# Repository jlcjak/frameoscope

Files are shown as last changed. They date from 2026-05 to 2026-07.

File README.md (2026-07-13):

# frameoscope
oscilloscope expansion card / module for framework laptops 

[frame.fasterscope.com](https://frame.fasterscope.com)

## Tech Specs
- sampling rate: 40MSPS
- bandwidth: 10MHz
- resolution: 8bit
- interface: usb2
- front end Rin: 8.5KOhm
- front end Cin: ~5pF
- input voltage: 0-5V (protected from reverse and high voltage)

## How to use
I have built and tested frameoscope, it works! I made it compatible with ngscopeclient.
Here is how to use it:
1. install [ngscopeclient](https://github.com/ngscopeclient/scopehal-apps/releases/)
2. plug in frameoscope and run: `curl -fsSL frame.fasterscope.com/install.sh | bash` (Source code in "/software")

That's it, now ngscopeclient should see frameoscope as an oscilloscope

to uninstall: `curl -fsSL frame.fasterscope.com/uninstall.sh | bash`

this works on ubuntu 24, for other distros clone this repo and ask codex(/your agent of choice) to make it work

The script installs, starts and enables a service that will flash frameoscope upon insertion
and start a bridge that translates the stream into ngscopeclient compatible packets

## Remarks
- The board is mainly comprimized of a TI adc, an iCE40 fpga and a usb PHY (FT232H).
- The fpga is used as an protocol tranlator between the busses on the usb PHY and adc.
- You can program the fpga directly over usb, through FT232H.
- There is no flash on the fpga so you need to reprogram it on reset or use iCE nvcm

## manufacturing
- all components are sourcable from lcsc, for easy assembly in china.
- use a 0.8mm board so you can solder on the usb connector

Nextpcb sponsored the first iteration of this project, thanks nextpcb. you can easily use them to make this for very cheap. They are professional, fast and cheap. [nextpcb.com](https://www.nextpcb.com/?code=Jak)

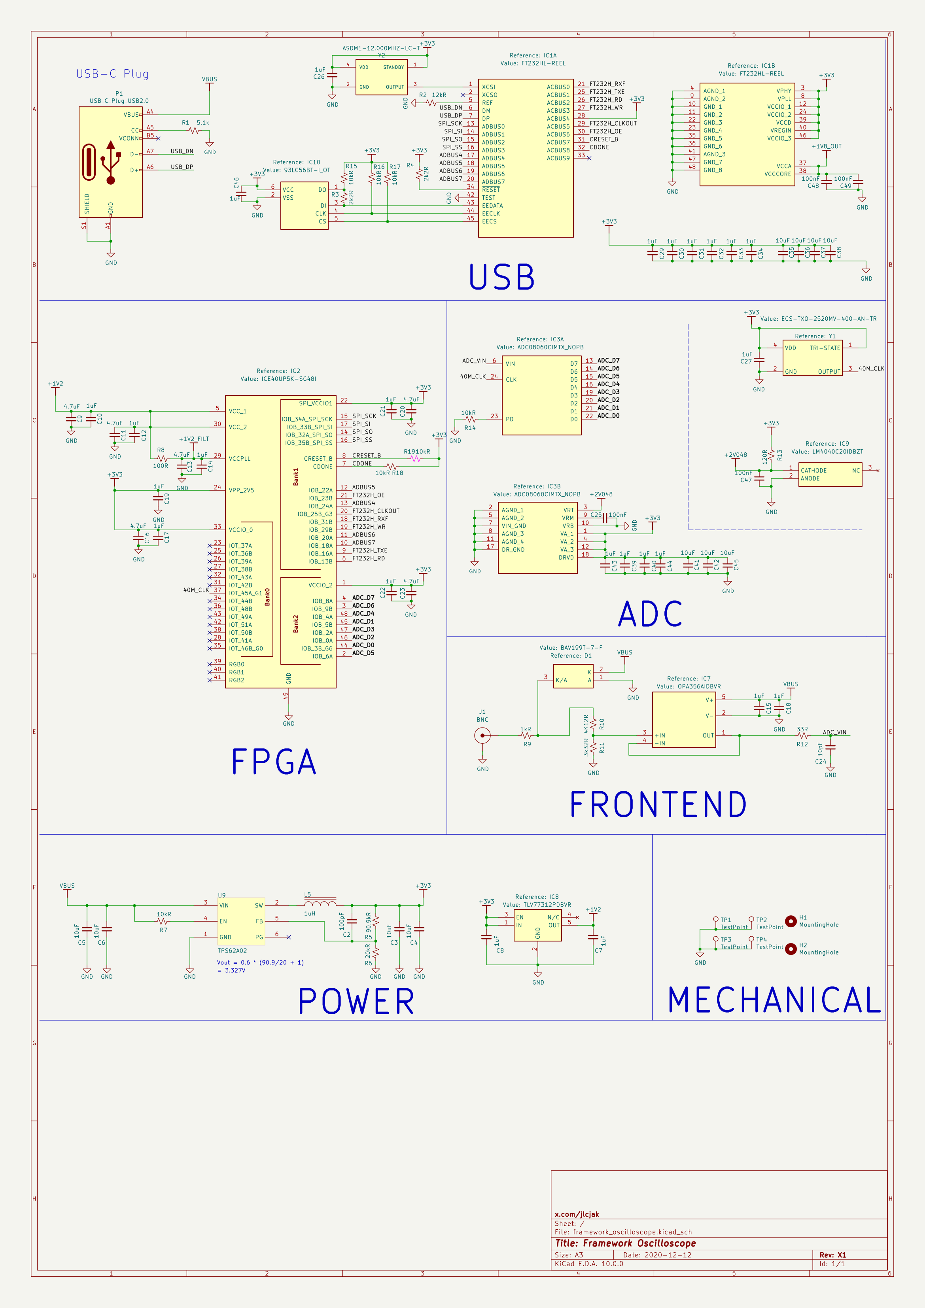
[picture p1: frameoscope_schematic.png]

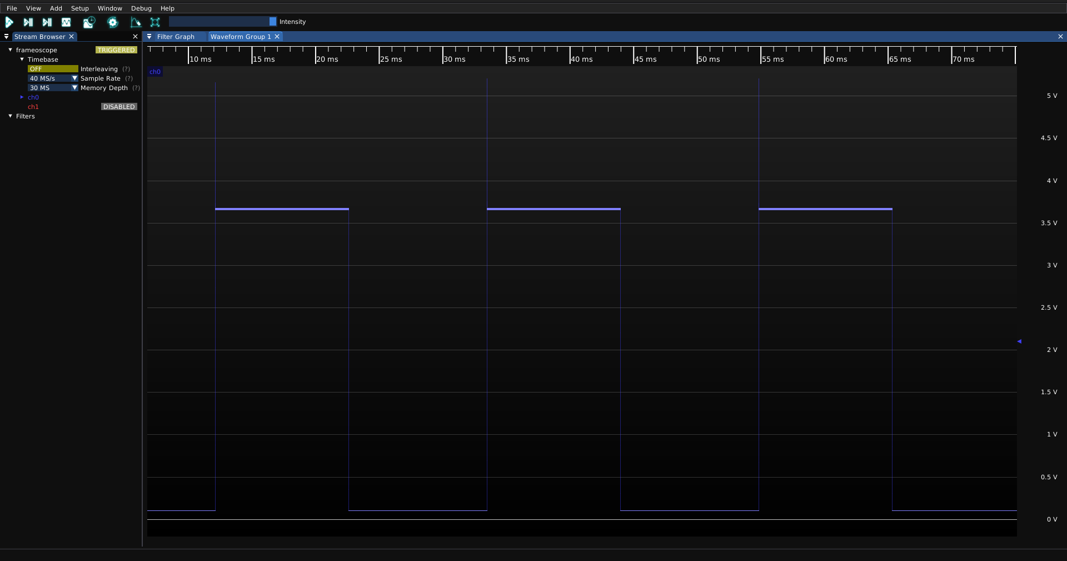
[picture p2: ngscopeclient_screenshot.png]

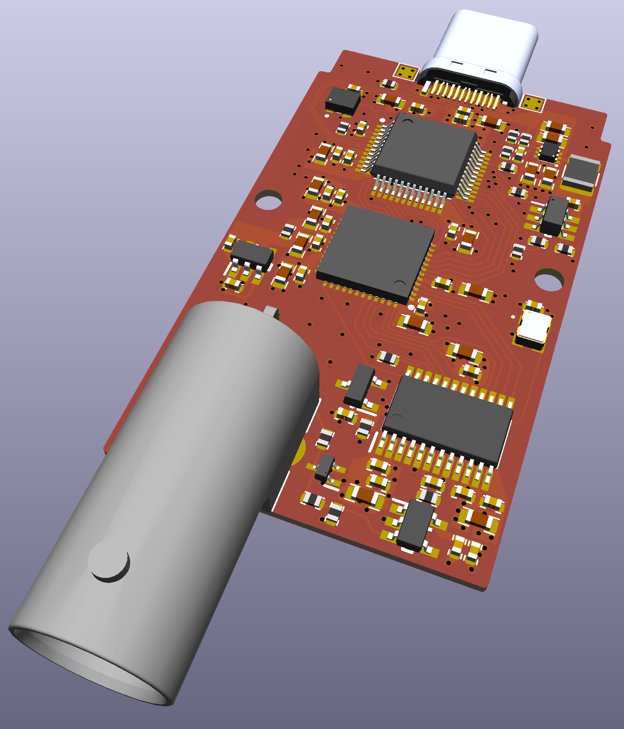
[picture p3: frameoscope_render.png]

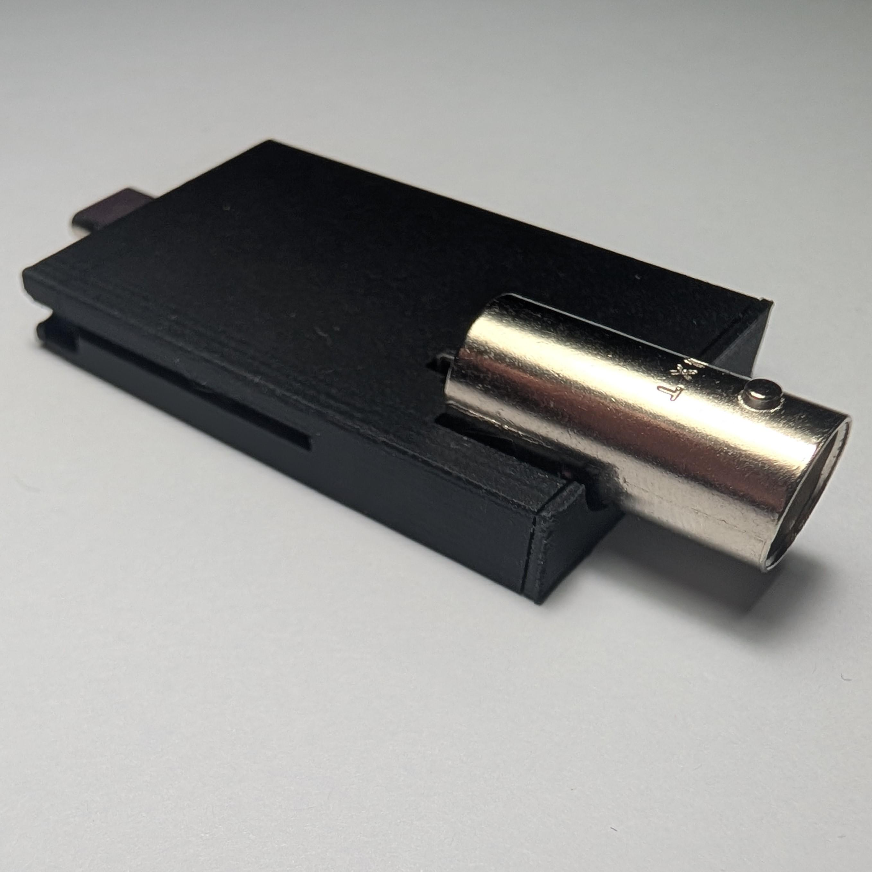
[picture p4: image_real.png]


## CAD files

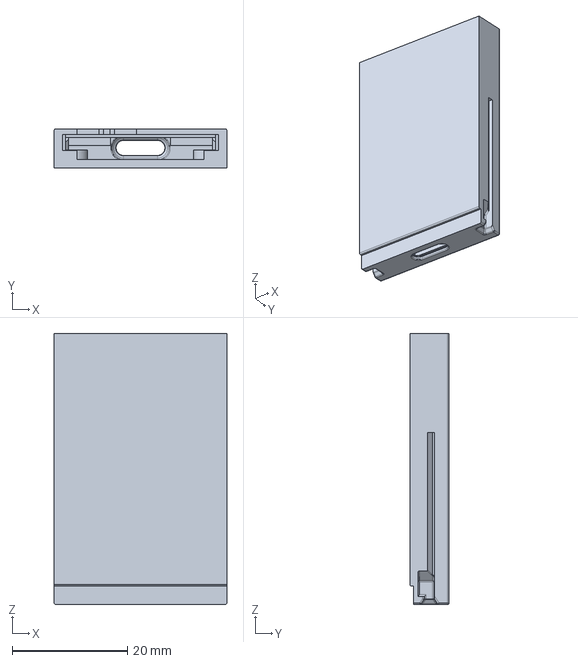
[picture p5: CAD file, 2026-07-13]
case_3d_models/case.step
30.0 x 6.80 x 47.0 mm

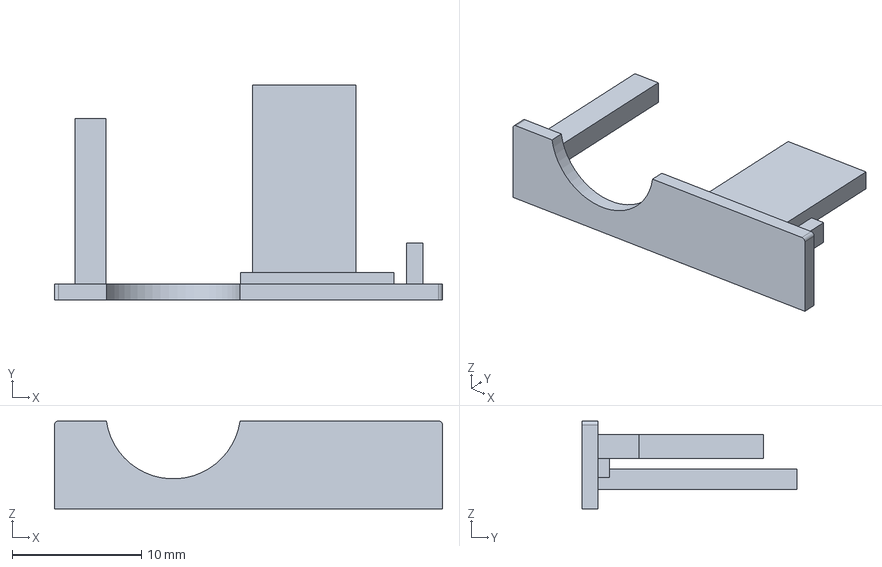
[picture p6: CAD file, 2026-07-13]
case_3d_models/case_cover.step
30.0 x 16.6 x 6.80 mm

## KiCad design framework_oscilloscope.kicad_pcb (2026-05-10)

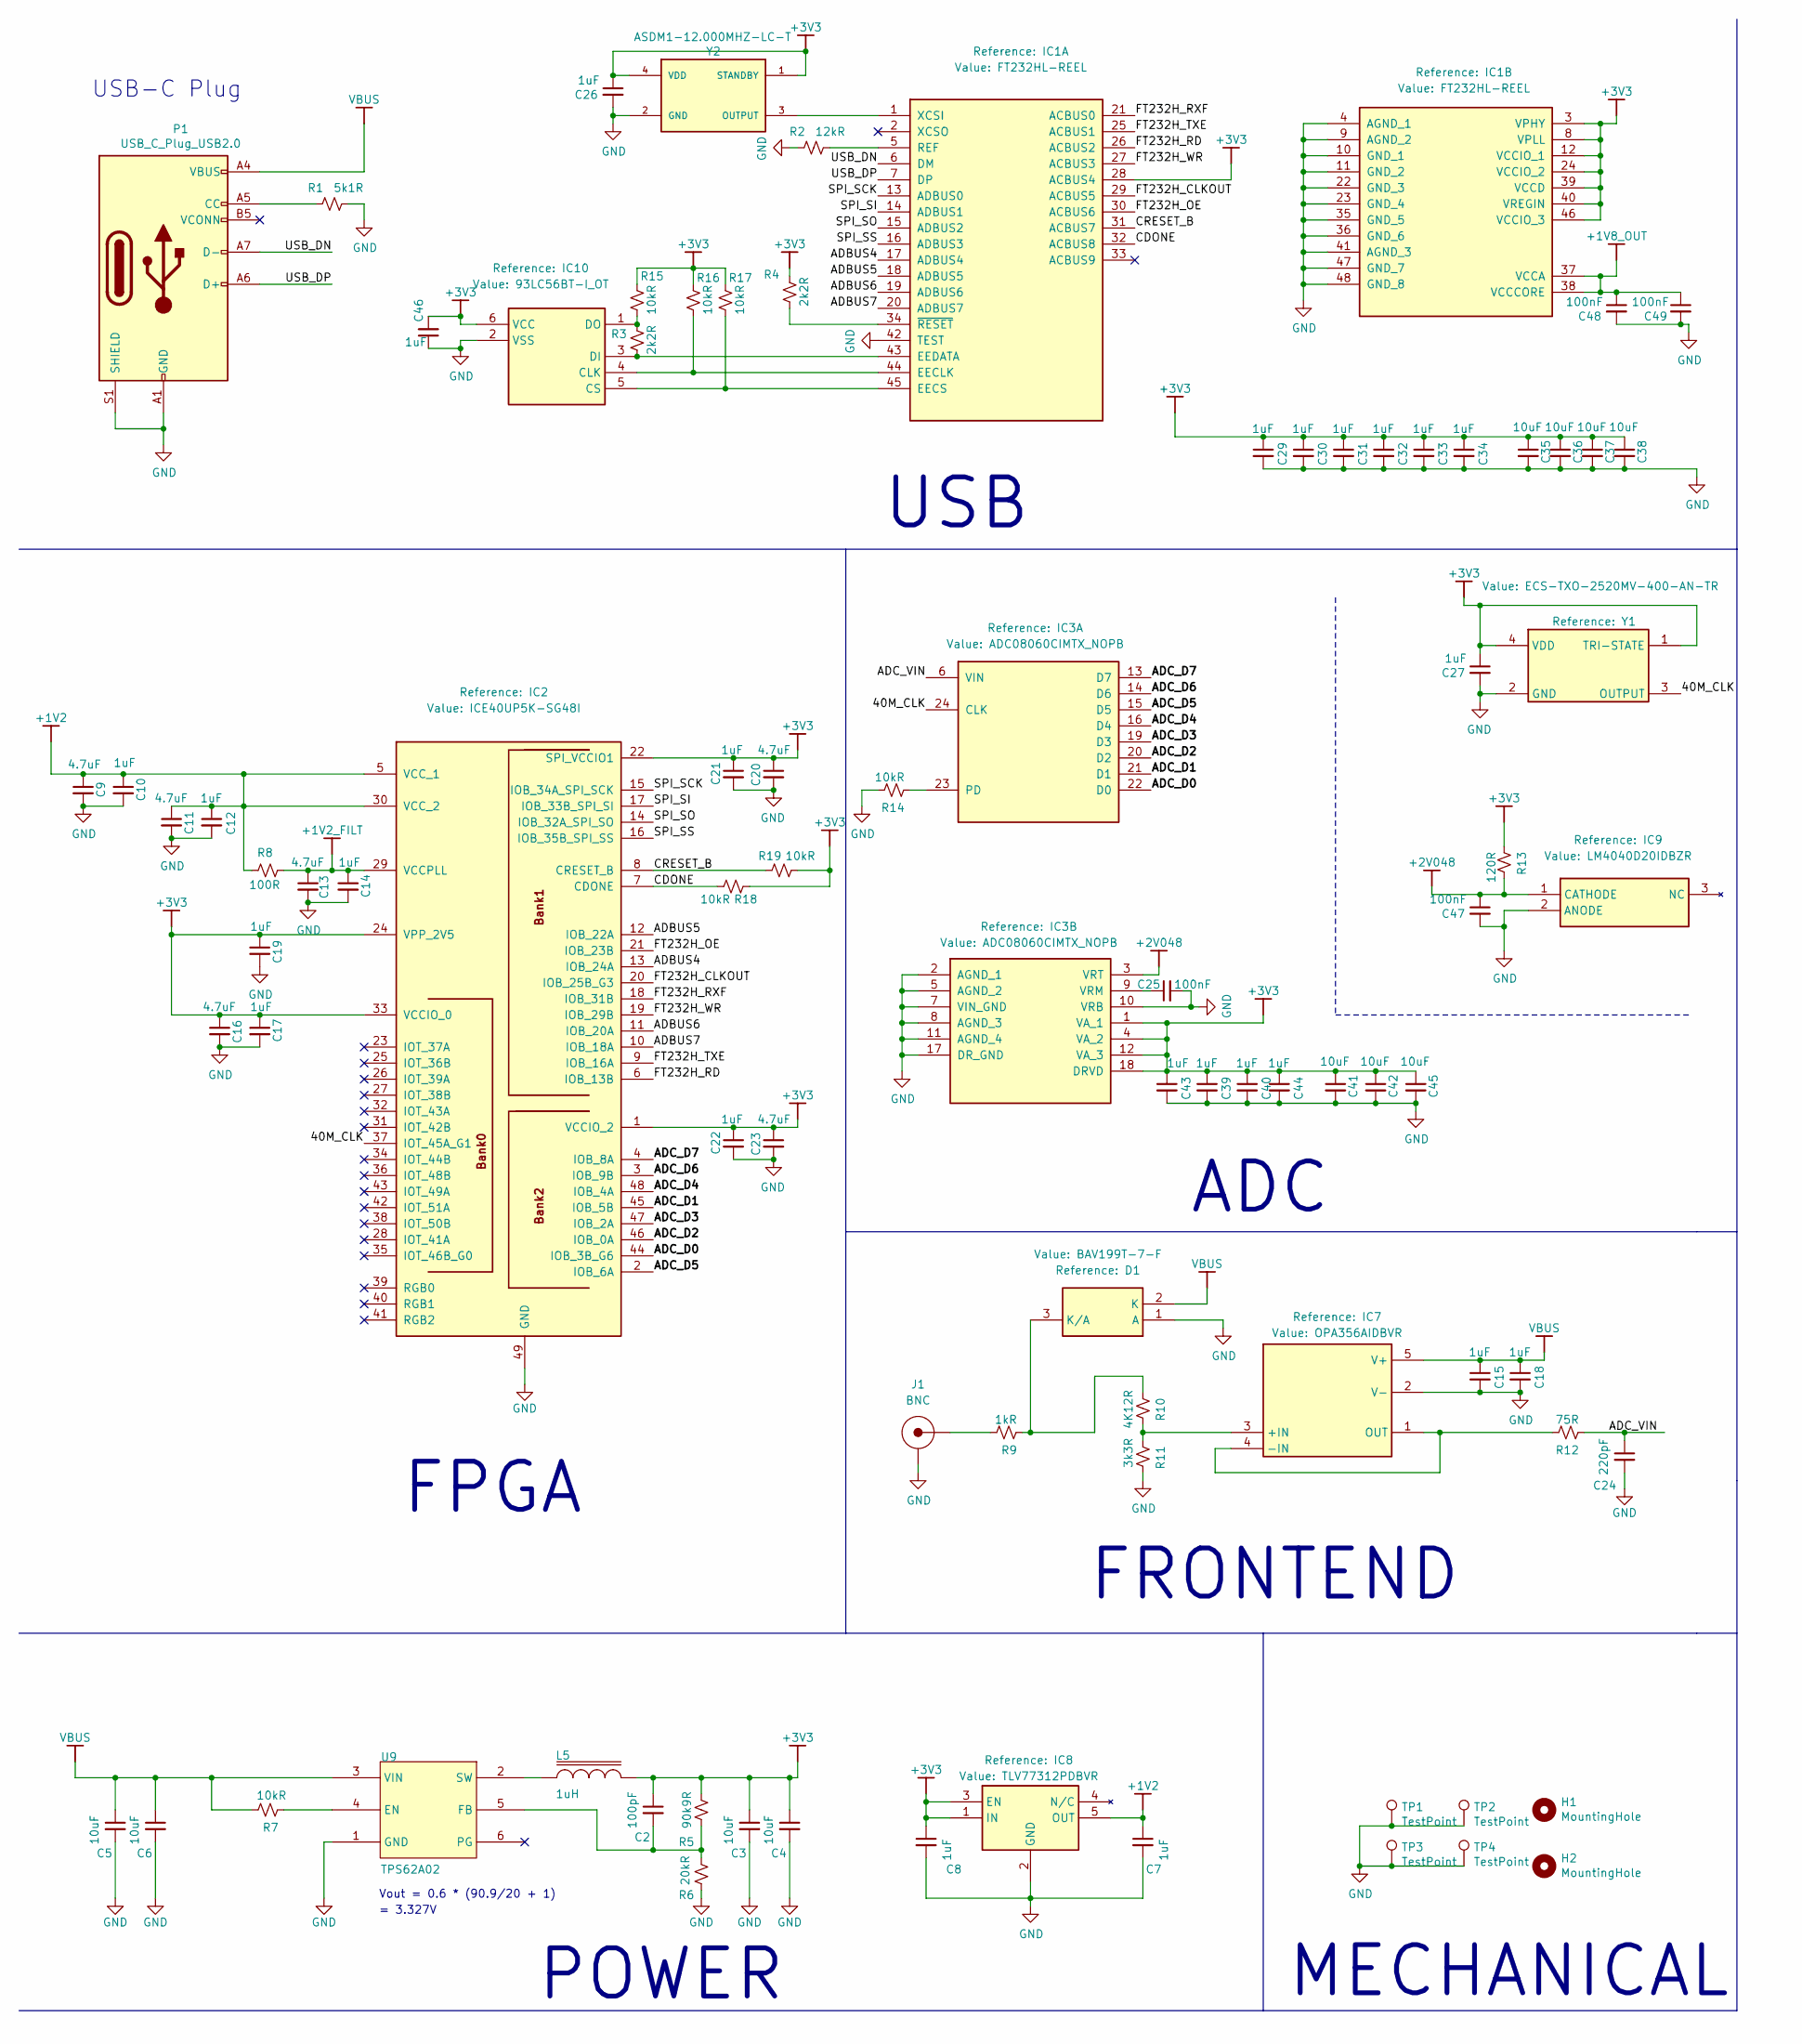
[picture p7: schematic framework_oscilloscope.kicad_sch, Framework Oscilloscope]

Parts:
C2: 100pF; 0402_1005Metric_CAP; MANUFACTURER PART NUMBER CC0402JRNPO9BN101
C3, C4, C5, C6, C35, C36, C37, C38, C41, C42, C45: 10uF; 0603_1608Metric_CAP; MANUFACTURER PART NUMBER CL10A106MQ8NNNC
C7, C8, C10, C12, C14, C15, C17, C18, C19, C21, C22, C26, C27, C29, C30, C31, C32, C33, C34, C39, C40, C43, C44, C46: 1uF; 0402_1005Metric_CAP; MANUFACTURER PART NUMBER CL05A105KO5NNNC
C9, C11, C13, C16, C20, C23: 4.7uF; 0603_1608Metric_CAP; MANUFACTURER PART NUMBER CL10A475KP8NNNC
C24: 220pF; 0402_1005Metric_CAP; MANUFACTURER PART NUMBER CC0402JRNPO9BN221
C25, C47, C48, C49: 100nF; 0402_1005Metric_CAP; MANUFACTURER PART NUMBER CL05B104KO5NNNC
D1: BAV199T-7-F; SOT50P160X90-3N; MANUFACTURER PART NUMBER BAV199T-7-F
H1, H2: MountingHole; MountingHole_2.2mm_M2
IC1: FT232HL-REEL; QFP50P900X900X160-48N; MANUFACTURER PART NUMBER FT232HL-REEL
IC2: ICE40UP5K-SG48I; QFN50P700X700X100-49N-D; MANUFACTURER PART NUMBER ICE40UP5K-SG48I
IC3: ADC08060CIMTX_NOPB; SOP65P640X120-24N; MANUFACTURER PART NUMBER ADC08060CIMTX/NOPB
IC7: OPA356AIDBVR; SOT95P280X145-5N; MANUFACTURER PART NUMBER OPA356AIDBVR
IC8: TLV77312PDBVR; SOT95P280X145-5N; MANUFACTURER PART NUMBER TLV77312PDBVR
IC9: LM4040D20IDBZR; SOT95P237X112-3N; MANUFACTURER PART NUMBER LM4040D20IDBZR
IC10: 93LC56BT-I_OT; SOT95P270X145-6N; MANUFACTURER PART NUMBER 93LC56BT-I/OT
J1: BNC; MOL_0731000105; MANUFACTURER PART NUMBER 73100-0105
L5: 1uH; 1210_3225Metric; MANUFACTURER PART NUMBER SRP3212-1R0M
P1: USB_C_Plug_USB2.0; USB_C_Plug_Molex_105444; MANUFACTURER PART NUMBER 105444-0001
R1: 5k1R; 0402_1005Metric; MANUFACTURER PART NUMBER RC0402FR-075K1L
R2: 12kR; 0402_1005Metric; MANUFACTURER PART NUMBER ERA2AEB123X
R3, R4: 2k2R; 0402_1005Metric; MANUFACTURER PART NUMBER RC0402JR-072K2L
R5: 90k9R; 0402_1005Metric; MANUFACTURER PART NUMBER RC0402FR-0790K9L
R6: 20kR; 0402_1005Metric; MANUFACTURER PART NUMBER RC0402FR-0720KL
R7, R14, R15, R16, R17, R18, R19: 10kR; 0402_1005Metric; MANUFACTURER PART NUMBER RC0402JR-0710KL
R8: 100R; 0402_1005Metric; MANUFACTURER PART NUMBER RC0402FR-07100RL
R9: 1kR; 0402_1005Metric; MANUFACTURER PART NUMBER RT0402FRE071KL
R10: 4K12R; 0402_1005Metric; MANUFACTURER PART NUMBER RT0402BRD074K12L
R11: 3k3R; 0402_1005Metric; MANUFACTURER PART NUMBER RT0402BRD073K3L
R12: 75R; 0402_1005Metric; MANUFACTURER PART NUMBER RC0402FR-0775RL
R13: 120R; 0402_1005Metric; MANUFACTURER PART NUMBER RC0402FR-0775RL
TP1, TP2, TP3, TP4: TestPoint; TestPoint_Pad_1.5x1.5mm
U9: TPS62A02; TI_SOT563_DRL0006A; MANUFACTURER PART NUMBER TPS62A02DRLR
Y1: ECS-TXO-2520MV-400-AN-TR; ECSTXO252033250ANTR; MANUFACTURER PART NUMBER ECS-TXO-2520MV-400-AN-TR
Y2: ASDM1-12.000MHZ-LC-T; XTAL_ASDM1-12.000MHZ-LC-T; MANUFACTURER PART NUMBER ASDM1-12.000MHZ-LC-T

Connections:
+1V2: C7.1, C9.1, C10.1, C11.1, C12.1, IC2.5 (VCC_1), IC2.30 (VCC_2), IC8.5 (OUT), R8.2
+1V2_FILT: C13.1, C14.1, IC2.29 (VCCPLL), R8.1
+1V8_OUT: C48.1, C49.1, IC1.37 (VCCA), IC1.38 (VCCCORE)
+2V048: C47.1, IC3.3 (VRT), IC9.1 (CATHODE), R13.1
+3V3: C2.1, C3.1, C4.1, C8.1, C16.1, C17.1, C19.1, C20.1, C21.1, C22.1, C23.1, C26.1, C27.1, C29.1, C30.1, C31.1, C32.1, C33.1, C34.1, C35.1, C36.1, C37.1, C38.1, C39.1, C40.1, C41.1, C42.1, C43.1, C44.1, C45.1, C46.2, IC1.3 (VPHY), IC1.8 (VPLL), IC1.12 (VCCIO_1), IC1.24 (VCCIO_2), IC1.28 (ACBUS4), IC1.39 (VCCD), IC1.40 (VREGIN), IC1.46 (VCCIO_3), IC2.1 (VCCIO_2), IC2.22 (SPI_VCCIO1), IC2.24 (VPP_2V5), IC2.33 (VCCIO_0), IC3.1 (VA_1), IC3.4 (VA_2), IC3.12 (VA_3), IC3.18 (DRVD), IC8.1 (IN), IC8.3 (EN), IC10.6 (VCC), L5.2, R4.2, R5.2, R13.2, R15.2, R16.2, R17.2, R18.1, R19.1, Y1.1 (TRI-STATE), Y1.4 (VDD), Y2.1 (STANDBY), Y2.4 (VDD)
/40M_CLK: IC2.37 (IOT_45A_G1), IC3.24 (CLK), Y1.3 (OUTPUT)
/ADBUS4: IC1.17 (ADBUS4), IC2.13 (IOB_24A)
/ADBUS5: IC1.18 (ADBUS5), IC2.12 (IOB_22A)
/ADBUS6: IC1.19 (ADBUS6), IC2.11 (IOB_20A)
/ADBUS7: IC1.20 (ADBUS7), IC2.10 (IOB_18A)
/ADC_D0: IC2.44 (IOB_3B_G6), IC3.22 (D0)
/ADC_D1: IC2.45 (IOB_5B), IC3.21 (D1)
/ADC_D2: IC2.46 (IOB_0A), IC3.20 (D2)
/ADC_D3: IC2.47 (IOB_2A), IC3.19 (D3)
/ADC_D4: IC2.48 (IOB_4A), IC3.16 (D4)
/ADC_D5: IC2.2 (IOB_6A), IC3.15 (D5)
/ADC_D6: IC2.3 (IOB_9B), IC3.14 (D6)
/ADC_D7: IC2.4 (IOB_8A), IC3.13 (D7)
/ADC_VIN: C24.1, IC3.6 (VIN), R12.2
/CDONE: IC1.32 (ACBUS8), IC2.7 (CDONE), R18.2
/CRESET_B: IC1.31 (ACBUS7), IC2.8 (CRESET_B), R19.2
/FT232H_CLKOUT: IC1.29 (ACBUS5), IC2.20 (IOB_25B_G3)
/FT232H_OE: IC1.30 (ACBUS6), IC2.21 (IOB_23B)
/FT232H_RD: IC1.26 (ACBUS2), IC2.6 (IOB_13B)
/FT232H_RXF: IC1.21 (ACBUS0), IC2.18 (IOB_31B)
/FT232H_TXE: IC1.25 (ACBUS1), IC2.9 (IOB_16A)
/FT232H_WR: IC1.27 (ACBUS3), IC2.19 (IOB_29B)
/SPI_SCK: IC1.13 (ADBUS0), IC2.15 (IOB_34A_SPI_SCK)
/SPI_SI: IC1.14 (ADBUS1), IC2.17 (IOB_33B_SPI_SI)
/SPI_SO: IC1.15 (ADBUS2), IC2.14 (IOB_32A_SPI_SO)
/SPI_SS: IC1.16 (ADBUS3), IC2.16 (IOB_35B_SPI_SS)
/USB_DN: IC1.6 (DM), P1.A7 (D-)
/USB_DP: IC1.7 (DP), P1.A6 (D+)
GND: C3.2, C4.2, C5.2, C6.2, C7.2, C8.2, C9.2, C10.2, C11.2, C12.2, C13.2, C14.2, C15.2, C16.2, C17.2, C18.2, C19.2, C20.2, C21.2, C22.2, C23.2, C24.2, C25.2, C26.2, C27.2, C29.2, C30.2, C31.2, C32.2, C33.2, C34.2, C35.2, C36.2, C37.2, C38.2, C39.2, C40.2, C41.2, C42.2, C43.2, C44.2, C45.2, C46.1, C47.2, C48.2, C49.2, D1.1 (A), IC1.4 (AGND_1), IC1.9 (AGND_2), IC1.10 (GND_1), IC1.11 (GND_2), IC1.22 (GND_3), IC1.23 (GND_4), IC1.35 (GND_5), IC1.36 (GND_6), IC1.41 (AGND_3), IC1.42 (TEST), IC1.47 (GND_7), IC1.48 (GND_8), IC2.49 (GND), IC3.2 (AGND_1), IC3.5 (AGND_2), IC3.7 (VIN_GND), IC3.8 (AGND_3), IC3.10 (VRB), IC3.11 (AGND_4), IC3.17 (DR_GND), IC7.2 (V-), IC8.2 (GND), IC9.2 (ANODE), IC10.2 (VSS), J1.2 (SHIELD), P1.A1 (GND), P1.A12 (GND), P1.B1 (GND), P1.B12 (GND), P1.S1 (SHIELD), R1.2, R2.1, R6.1, R11.1, R14.1, TP1.1 (1_1), TP2.1 (1_1), TP3.1 (1_1), TP4.1 (1_1), U9.1 (GND), Y1.2 (GND), Y2.2 (GND)
unnamed: D1.3 (K/A), R9.2, R10.2
unnamed: IC1.5 (REF), R2.2
unnamed: IC1.1 (XCSI), Y2.3 (OUTPUT)
unnamed: IC1.34 (~RESET), R4.1
unnamed: IC3.23 (PD), R14.2
unnamed: C25.1, IC3.9 (VRM)
unnamed: IC7.3 (+IN), R10.1, R11.2
unnamed: IC7.1 (OUT), IC7.4 (-IN), R12.1
unnamed: IC1.44 (EECLK), IC10.4 (CLK), R16.1
unnamed: IC1.45 (EECS), IC10.5 (CS), R17.1
unnamed: IC1.43 (EEDATA), IC10.3 (DI), R3.1
unnamed: IC10.1 (DO), R3.2, R15.1
unnamed: J1.1 (Signal), R9.1
unnamed: P1.A5 (CC), R1.1
unnamed: R7.2, U9.4 (EN)
unnamed: C2.2, R5.1, R6.2, U9.5 (FB)
unnamed: L5.1, U9.2 (SW)
VBUS: C5.1, C6.1, C15.1, C18.1, D1.2 (K), IC7.5 (V+), P1.A4 (VBUS), P1.A9 (VBUS), P1.B4 (VBUS), P1.B9 (VBUS), R7.1, U9.3 (VIN)

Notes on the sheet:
USB-C Plug
Vout = 0.6 * (90.9/20 + 1)
USB
= 3.327V
FRONTEND
ADC
MECHANICAL
POWER
FPGA

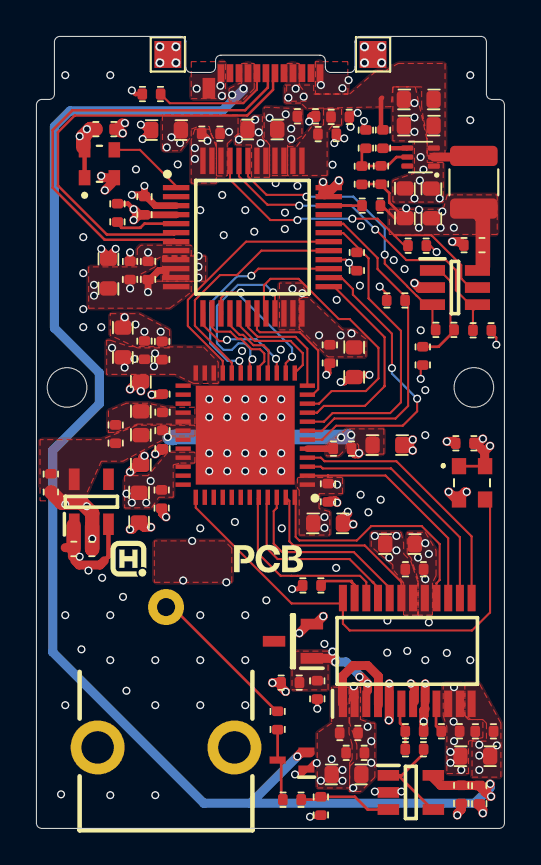
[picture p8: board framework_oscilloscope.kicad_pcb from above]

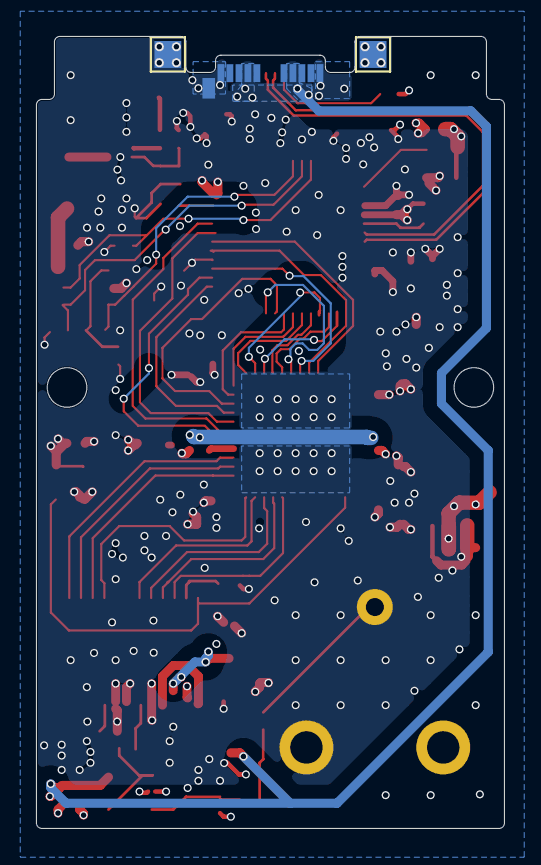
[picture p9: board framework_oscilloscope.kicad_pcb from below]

Board: 4 copper layers, 26.0 x 44.0 mm, 87 parts (2 on the bottom side), 52 nets.

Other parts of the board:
LOGO1: NextPCB

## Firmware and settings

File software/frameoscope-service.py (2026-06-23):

#!/usr/bin/env python3
from __future__ import annotations

import argparse
import os
import re
import secrets
import shutil
import signal
import subprocess
import sys
import tarfile
import time
from datetime import datetime
from pathlib import Path

VID = 0x0403
PID = 0x6014
DEFAULT_URL = "ftdi://ftdi:232h/1"
FRAMEOSCOPE_PRODUCT_PREFIX = "Frameoscope"
FRAMEOSCOPE_PRODUCT = "Frameoscope 40MSPS"
FRAMEOSCOPE_MANUFACTURER = "FasterScope"
GENERIC_PRODUCT = "Single RS232-HS"
GENERIC_MANUFACTURER = "FTDI"

ADBUS_SCK = 0x01
ADBUS_MOSI = 0x02
ADBUS_MISO = 0x04
ADBUS_CS_N = 0x08
LOW_DIR = ADBUS_SCK | ADBUS_MOSI | ADBUS_CS_N
LOW_IDLE = ADBUS_CS_N

ACBUS_CRESET_N = 0x80
HIGH_DIR = ACBUS_CRESET_N
HIGH_IDLE = ACBUS_CRESET_N

MPSSE_CHUNK = 65536
APP_DIR = Path(__file__).resolve().parent
PAYLOAD = APP_DIR / "frameoscope-payload.tar.gz"
BITSTREAM = APP_DIR / "top_adc_40m_stream.bin"
BRIDGE_SRC = APP_DIR / "frameoscope_ngscope_bridge.c"
BRIDGE_EXE = APP_DIR / "frameoscope_ngscope_bridge"

stopping = False
bridge_process: subprocess.Popen[bytes] | None = None


def log(message: str) -> None:
    print(f"[frameoscope] {message}", flush=True)


def die(message: str, code: int = 1) -> None:
    log(f"error: {message}")
    raise SystemExit(code)


def safe_extract_tar(path: Path, target_dir: Path) -> None:
    root = target_dir.resolve()
    with tarfile.open(path, "r:gz") as tar:
        for member in tar.getmembers():
            dest = (target_dir / member.name).resolve()
            if dest != root and not str(dest).startswith(str(root) + os.sep):
                die(f"payload contains unsafe path: {member.name}")
        tar.extractall(target_dir)


def ensure_payload() -> None:
    if BITSTREAM.is_file() and BRIDGE_SRC.is_file():
        return
    if not PAYLOAD.is_file():
        die(f"missing payload: {PAYLOAD}")
    log(f"extracting payload from {PAYLOAD}")
    safe_extract_tar(PAYLOAD, APP_DIR)
    if not BITSTREAM.is_file() or not BRIDGE_SRC.is_file():
        die("payload did not provide bridge source and 40 MSPS bitstream")


def require_command(name: str) -> str:
    path = shutil.which(name)
    if not path:
        die(f"missing command `{name}`; install gcc, pkg-config, and libusb-1.0-dev")
    return path


def pkg_config(args: list[str]) -> list[str]:
    try:
        out = subprocess.check_output(["pkg-config", *args, "libusb-1.0"], text=True)
        return out.split()
    except Exception:
        return []


def compile_bridge() -> Path:
    ensure_payload()
    if BRIDGE_EXE.is_file() and BRIDGE_EXE.stat().st_mtime >= BRIDGE_SRC.stat().st_mtime:
        return BRIDGE_EXE

    require_command("gcc")
    cflags = pkg_config(["--cflags"])
    libs = pkg_config(["--libs"])
    if not libs:
        libs = ["-lusb-1.0"]
    if not cflags and Path("/usr/include/libusb-1.0").is_dir():
        cflags = ["-I/usr/include/libusb-1.0"]

    cmd = [
        "gcc",
        "-O3",
        "-Wall",
        "-Wextra",
        "-pthread",
        *cflags,
        "-o",
        str(BRIDGE_EXE),
        str(BRIDGE_SRC),
        *libs,
    ]
    log("compiling ngscope bridge")
    try:
        subprocess.check_call(cmd, cwd=APP_DIR)
    except subprocess.CalledProcessError as exc:
        die(f"bridge compile failed with exit code {exc.returncode}")
    BRIDGE_EXE.chmod(0o755)
    return BRIDGE_EXE


def import_ftdi():
    try:
        from pyftdi.ftdi import Ftdi
    except Exception as exc:
        die(f"missing pyftdi: {exc}. Re-run install.sh so the venv is created.")
    return Ftdi


def is_frameoscope_product(product: str | None) -> bool:
    return bool(product and product.startswith(FRAMEOSCOPE_PRODUCT_PREFIX))


def safe_name(text: str) -> str:
    return re.sub(r"[^A-Za-z0-9_.-]+", "_", text)[:80] or "unknown"


def make_serial() -> str:
    return "FS" + secrets.token_hex(4).upper()


def list_ft232h_devices() -> list[dict[str, object]]:
    Ftdi = import_ftdi()
    try:
        found = Ftdi.list_devices("ftdi://ftdi:232h/?")
    except Exception as exc:
        log(f"FT232H enumeration failed: {exc}")
        return []

    devices: list[dict[str, object]] = []
    single = len(found) == 1
    for index, (desc, interface) in enumerate(found, 1):
        serial = getattr(desc, "sn", None) or ""
        product = getattr(desc, "description", None) or ""
        if serial:
            url = f"ftdi://ftdi:232h:{serial}/1"
        elif single:
            url = DEFAULT_URL
        else:
            url = None
        devices.append({
            "index": index,
            "url": url,
            "serial": serial,
            "product": product,
            "bus": getattr(desc, "bus", None),
            "address": getattr(desc, "address", None),
            "interface": interface,
            "tagged": is_frameoscope_product(product),
        })
    return devices


def find_frameoscope_url() -> str | None:
    devices = [d for d in list_ft232h_devices() if d["tagged"]]
    if not devices:
        return None
    if len(devices) > 1:
        log("multiple tagged Frameoscope devices found; using the first one")
    url = devices[0]["url"]
    if not isinstance(url, str):
        log("tagged Frameoscope device has no serial and cannot be selected safely")
        return None
    return url


def wait_for_frameoscope_url(poll_s: float) -> str | None:
    announced = False
    while not stopping:
        url = find_frameoscope_url()
        if url:
            if announced:
                log("tagged Frameoscope FT232H detected")
            return url
        if not announced:
            log("waiting for tagged Frameoscope FT232H")
            announced = True
        time.sleep(poll_s)
    return None


class Ice40MpsseProgrammer:
    def __init__(self, url: str, frequency: float) -> None:
        self.Ftdi = import_ftdi()
        self.url = url
        self.frequency = frequency
        self.ftdi = self.Ftdi()
        self.low = LOW_IDLE
        self.high = HIGH_IDLE
        self.opened = False

    def open(self) -> None:
        direction = LOW_DIR | (HIGH_DIR << 8)
        initial = LOW_IDLE | (HIGH_IDLE << 8)
        actual = self.ftdi.open_mpsse_from_url(
            self.url,
            direction=direction,
            initial=initial,
            frequency=self.frequency,
            latency=2,
        )
        self.opened = True
        self.ftdi.enable_adaptive_clock(False)
        self.ftdi.enable_3phase_clock(False)
        self.ftdi.purge_buffers()
        log(f"MPSSE opened at {actual:.0f} Hz")
        self.set_pins(cs_n=True, creset_n=True)

    def close(self) -> None:
        if not self.opened:
            return
        try:
            self.set_pins(cs_n=True, creset_n=True)
        finally:
            self.ftdi.close()
            self.opened = False

    def set_pins(self, *, cs_n: bool | None = None, creset_n: bool | None = None) -> None:
        if cs_n is not None:
            self.low = self.low | ADBUS_CS_N if cs_n else self.low & ~ADBUS_CS_N
        if creset_n is not None:
            self.high = self.high | ACBUS_CRESET_N if creset_n else self.high & ~ACBUS_CRESET_N
        cmd = bytes((
            self.Ftdi.SET_BITS_LOW, self.low, LOW_DIR,
            self.Ftdi.SET_BITS_HIGH, self.high, HIGH_DIR,
        ))
        self.ftdi.write_data(cmd)

    def spi_write(self, data: bytes) -> None:
        view = memoryview(data)
        while view:
            chunk = view[:MPSSE_CHUNK]
            n = len(chunk)
            cmd = bytearray((
                self.Ftdi.WRITE_BYTES_NVE_MSB,
                (n - 1) & 0xff,
                ((n - 1) >> 8) & 0xff,
            ))
            cmd.extend(chunk)
            self.ftdi.write_data(cmd)
            view = view[n:]

    def dummy_clocks(self) -> None:
        self.spi_write(b"\xff" * 6)
        self.ftdi.write_data(bytes((self.Ftdi.WRITE_BITS_NVE_MSB, 0, 0xff)))

    def program_sram(self, bitstream: Path) -> None:
        data = bitstream.read_bytes()
        log(f"programming FPGA SRAM from {bitstream.name} ({len(data)} bytes)")
        self.set_pins(cs_n=True, creset_n=True)
        time.sleep(0.100)
        self.set_pins(cs_n=False, creset_n=False)
        time.sleep(0.001)
        self.set_pins(cs_n=False, creset_n=True)
        time.sleep(0.002)
        for offset in range(0, len(data), 4096):
            self.spi_write(data[offset:offset + 4096])
        self.dummy_clocks()
        self.set_pins(cs_n=True, creset_n=True)
        time.sleep(0.010)
        log("FPGA SRAM programming complete")


def flash_fpga(url: str, spi_frequency: float) -> None:
    ensure_payload()
    programmer = Ice40MpsseProgrammer(url, spi_frequency)
    try:
        programmer.open()
        programmer.program_sram(BITSTREAM)
    finally:
        programmer.close()


def terminate_child() -> None:
    global bridge_process
    proc = bridge_process
    if proc and proc.poll() is None:
        proc.terminate()
        try:
            proc.wait(timeout=3)
        except subprocess.TimeoutExpired:
            proc.kill()
            proc.wait(timeout=3)
    bridge_process = None


def on_signal(signum, frame) -> None:  # type: ignore[no-untyped-def]
    global stopping
    stopping = True
    terminate_child()


def run_service(args: argparse.Namespace) -> int:
    signal.signal(signal.SIGINT, on_signal)
    signal.signal(signal.SIGTERM, on_signal)

    bridge = compile_bridge()
    log("ready for ngscopeclient connection: frameoscope:dslabs:twinlan:localhost:5025:5026")

    while not stopping:
        url = wait_for_frameoscope_url(args.poll_seconds)
        if not url:
            break
        try:
            flash_fpga(url, args.spi_frequency)
        except Exception as exc:
            log(f"flash failed: {exc}; retrying")
            time.sleep(args.retry_seconds)
            continue

        cmd = [
            str(bridge),
            "--sample-rate",
            str(args.sample_rate),
            "--ring-mib",
            str(args.ring_mib),
        ]
        log("starting ngscope bridge")
        global bridge_process
        bridge_process = subprocess.Popen(cmd, cwd=APP_DIR)
        while not stopping and bridge_process.poll() is None:
            time.sleep(0.5)
        if stopping:
            break
        rc = bridge_process.returncode
        bridge_process = None
        log(f"bridge exited with code {rc}; waiting before retry")
        time.sleep(args.retry_seconds)

    terminate_child()
    return 0


def open_eeprom(url: str, size: int):
    try:
        from pyftdi.eeprom import FtdiEeprom
    except Exception as exc:
        die(f"missing pyftdi EEPROM support: {exc}")
    ee = FtdiEeprom()
    ee.open(url, size=size)
    return ee


def backup_eeprom(ee, label: str) -> Path:
    stamp = datetime.utcnow().strftime("%Y%m%d-%H%M%S")
    backup = APP_DIR / f"ft232h-eeprom-before-{safe_name(label)}-{stamp}.bin"
    backup.write_bytes(bytes(ee.data))
    log(f"saved EEPROM backup to {backup}")
    return backup


def maybe_reset_eeprom_device(ee) -> None:
    try:
        from usb.core import USBError
    except Exception:
        USBError = Exception  # type: ignore
    try:
        ee.reset_device()
    except USBError as exc:  # type: ignore[misc]
        if getattr(exc, "errno", None) != 2:
            raise


def ensure_valid_eeprom_image(ee, args: argparse.Namespace) -> None:
    props = ee.properties
    if args.initialize or not props:
        log("initializing EEPROM image before applying settings")
        ee._eeprom[:] = b"\x00" * len(ee._eeprom)
        ee.initialize()
        ee.set_property("power_max", args.power_max)
        ee.set_property("self_powered", False)
        ee.set_property("remote_wakeup", False)
        ee.set_property("suspend_pull_down", False)
        ee.set_property("out_isochronous", False)
        ee.set_property("in_isochronous", False)


def write_frameoscope_tag(url: str, serial: str, args: argparse.Namespace) -> None:
    if not args.yes:
        die("EEPROM programming is persistent. Re-run with --yes to write tags.")

    ee = open_eeprom(url, args.size)
    try:
        backup_eeprom(ee, serial or url)
        ensure_valid_eeprom_image(ee, args)

        ee.set_property("channel_a_type", "FIFO")
        ee.set_property("channel_a_driver", "D2XX")
        ee.set_manufacturer_name(args.manufacturer)
        ee.set_product_name(args.product)
        if not serial:
            new_serial = make_serial()
            log(f"assigning serial {new_serial}")
            ee.set_serial_number(new_serial)
        ee.sync()
        log(f"writing Frameoscope EEPROM tag to {url}")
        ee.commit(dry_run=False)
        maybe_reset_eeprom_device(ee)
    finally:
        ee.close()


def remove_frameoscope_tag(url: str, serial: str, args: argparse.Namespace) -> None:
    if not args.yes:
        die("EEPROM programming is persistent. Re-run with --yes to remove tags.")

    ee = open_eeprom(url, args.size)
    try:
        backup_eeprom(ee, serial or url)
        ensure_valid_eeprom_image(ee, args)
        ee.set_manufacturer_name(args.manufacturer)
        ee.set_product_name(args.product)
        ee.sync()
        log(f"removing Frameoscope EEPROM tag from {url}")
        ee.commit(dry_run=False)
        maybe_reset_eeprom_device(ee)
    finally:
        ee.close()


def tag_devices(args: argparse.Namespace) -> int:
    devices = list_ft232h_devices()
    if not devices:
        log("no FT232H devices found to tag")
        return 0

    wrote = 0
    skipped = 0
    for dev in devices:
        product = str(dev["product"])
        serial = str(dev["serial"])
        url = dev["url"]
        if dev["tagged"] and not args.refresh_tagged:
            log(f"already tagged: serial={serial or '-'} product={product!r}")
            skipped += 1
            continue
        if not isinstance(url, str):
            log(f"skipping device without unique serial: product={product!r}")
            skipped += 1
            continue
        log(f"tagging FT232H serial={serial or '-'} product={product!r}")
        write_frameoscope_tag(url, serial, args)
        wrote += 1
        time.sleep(0.5)

    log(f"tagging complete: wrote={wrote} skipped={skipped}")
    return 0


def untag_devices(args: argparse.Namespace) -> int:
    devices = [d for d in list_ft232h_devices() if d["tagged"]]
    if not devices:
        log("no tagged Frameoscope devices found")
        return 0

    for dev in devices:
        url = dev["url"]
        if not isinstance(url, str):
            log(f"skipping tagged device without unique serial: product={dev['product']!r}")
            continue
        remove_frameoscope_tag(url, str(dev["serial"]), args)
        time.sleep(0.5)
    log("Frameoscope tags removed from connected devices")
    return 0


def program_eeprom(args: argparse.Namespace) -> int:
    return tag_devices(args)


def doctor(args: argparse.Namespace) -> int:
    ensure_payload()
    print(f"app dir: {APP_DIR}")
    print(f"payload: {'ok' if PAYLOAD.is_file() else 'missing'}")
    print(f"bitstream: {'ok' if BITSTREAM.is_file() else 'missing'}")
    print(f"bridge source: {'ok' if BRIDGE_SRC.is_file() else 'missing'}")
    print(f"gcc: {shutil.which('gcc') or 'missing'}")
    print(f"pkg-config: {shutil.which('pkg-config') or 'missing'}")
    try:
        devices = list_ft232h_devices()
        print("pyftdi: ok")
        if not devices:
            print(f"device {VID:04x}:{PID:04x}: not present")
        for dev in devices:
            print(
                "device "
                f"serial={dev['serial'] or '-'} "
                f"product={dev['product']!r} "
                f"tagged={'yes' if dev['tagged'] else 'no'} "
                f"url={dev['url'] or '-'}"
            )
    except SystemExit:
        print("pyftdi: missing")
    return 0


def main(argv: list[str] | None = None) -> int:
    parser = argparse.ArgumentParser(description="Frameoscope ngscopeclient runtime service")
    sub = parser.add_subparsers(dest="cmd", required=True)

    run = sub.add_parser("run", help="flash FPGA then run/retry the ngscope bridge")
    run.add_argument("--url", default=DEFAULT_URL)
    run.add_argument("--sample-rate", type=int, default=40_000_000)
    run.add_argument("--ring-mib", type=int, default=192)
    run.add_argument("--spi-frequency", type=float, default=6_000_000)
    run.add_argument("--poll-seconds", type=float, default=1.0)
    run.add_argument("--retry-seconds", type=float, default=2.0)
    run.set_defaults(func=run_service)

    eeprom = sub.add_parser("program-eeprom", help="alias for tag-devices")
    eeprom.set_defaults(func=program_eeprom, refresh_tagged=True,
                        manufacturer=FRAMEOSCOPE_MANUFACTURER,
                        product=FRAMEOSCOPE_PRODUCT)

    tag = sub.add_parser("tag-devices", help="persistently mark connected FT232H devices as Frameoscope")
    tag.add_argument("--size", type=int, default=256)
    tag.add_argument("--power-max", type=int, default=500)
    tag.add_argument("--manufacturer", default=FRAMEOSCOPE_MANUFACTURER)
    tag.add_argument("--product", default=FRAMEOSCOPE_PRODUCT)
    tag.add_argument("--initialize", action="store_true")
    tag.add_argument("--refresh-tagged", action="store_true")
    tag.add_argument("--yes", action="store_true")
    tag.set_defaults(func=tag_devices)

    untag = sub.add_parser("untag-devices", help="remove Frameoscope product tag from connected devices")
    untag.add_argument("--size", type=int, default=256)
    untag.add_argument("--power-max", type=int, default=500)
    untag.add_argument("--manufacturer", default=GENERIC_MANUFACTURER)
    untag.add_argument("--product", default=GENERIC_PRODUCT)
    untag.add_argument("--initialize", action="store_true")
    untag.add_argument("--yes", action="store_true")
    untag.set_defaults(func=untag_devices)

    for p in (eeprom,):
        p.add_argument("--size", type=int, default=256)
        p.add_argument("--power-max", type=int, default=500)
        p.add_argument("--product", default=FRAMEOSCOPE_PRODUCT)
        p.add_argument("--manufacturer", default=FRAMEOSCOPE_MANUFACTURER)
        p.add_argument("--initialize", action="store_true")
        p.add_argument("--yes", action="store_true")
    eeprom.set_defaults(func=program_eeprom)

    diag = sub.add_parser("doctor", help="check local files and dependencies")
    diag.set_defaults(func=doctor)

    args = parser.parse_args(argv)
    return args.func(args)


if __name__ == "__main__":
    raise SystemExit(main())

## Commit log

2026-05-02 cleaned up layout layers
    [framework_oscilloscope.kicad_pcb]
2026-05-02 cleaned up schematics
    [framework_oscilloscope.kicad_sch]
2026-05-02 cleanup, and a little routing
    [framework_oscilloscope.kicad_pcb, framework_oscilloscope.kicad_sch]
2026-05-02 small sch tweek, almost done routing
    [framework_oscilloscope.kicad_pcb, framework_oscilloscope.kicad_sch]
2026-05-02 done routing
    [framework_oscilloscope.kicad_pcb, framework_oscilloscope.kicad_sch]
2026-05-02 fixed emc errors, fixed drc errors
    [framework_oscilloscope.kicad_pcb, framework_oscilloscope.kicad_sch]
2026-05-02 changed layout frame size
    [framework_oscilloscope.kicad_pcb]
2026-05-02 added pull ups to eeprom->ftdi spi, as per reference design (tri state pins on FT232 SPI)
    [framework_oscilloscope.kicad_pcb, framework_oscilloscope.kicad_sch]
2026-05-02 changed stackup name to a similar 0.8mm one
    [framework_oscilloscope.kicad_pcb]
2026-05-03 updated frameoscope_3d.png
2026-05-03 removed frameoscope_3d.png
2026-05-03 readded frameoscope_3d.png
2026-05-03 added frameoscdope_render.png
2026-05-04 fixed FT232-FPGA connections
    [framework_oscilloscope.kicad_pcb, framework_oscilloscope.kicad_sch]
2026-05-04 updated frameoscope_schematic.png
2026-05-04 changed front end bandwidth limit
    [framework_oscilloscope.kicad_sch]
2026-05-09 added part numbers for passives
    [framework_oscilloscope.kicad_pcb, framework_oscilloscope.kicad_sch]
2026-05-10 improved dfm
    [framework_oscilloscope.kicad_pcb, framework_oscilloscope.kicad_sch]
2026-06-21 Update README with usage instructions for frameoscope
2026-06-23 updated software to only flashed tagged devices
2026-07-13 added case 3d models
    [case.step, case_cover.step]
